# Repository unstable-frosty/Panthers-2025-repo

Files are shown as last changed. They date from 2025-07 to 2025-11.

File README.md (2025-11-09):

# Table of contents

- [Introduction](#Introduction)
- <a href="https://github.com/unstable-frosty/Panthers-2025-repo/tree/main/models">3D Models</a>
- <a href="https://github.com/unstable-frosty/Panthers-2025-repo/tree/main/schemes">Schematics</a>
- <a href="https://github.com/unstable-frosty/Panthers-2025-repo/tree/main/src">Coding Documentation</a>
- <a href="https://github.com/unstable-frosty/Panthers-2025-repo/blob/main/Development%20stages%20and%20work%20ethic.md">Development Stages and Work Ethic</a>
- <a href="https://github.com/unstable-frosty/Panthers-2025-repo/blob/main/Final%20plan%20strategy.md">Final plan strategy</a>
- <a href="https://github.com/unstable-frosty/Panthers-2025-repo/tree/main/v-photos">Car photos</a>
- <a href="https://github.com/unstable-frosty/Panthers-2025-repo/tree/main/t-photos">Team photos</a>

---

# Introduction
Hello everyone! 
Welcome to our GitHub repository. In this repo, we will be documenting our journey in building our obstacle avoiding car, while also sharing some details about our software, design struggles and how we managed to overcome these challenges. We hope to inspire everyone who reads this documentation and spark an idea for their future solutions. Thank you for your visit, enjoy the ride!

***

## Team members

Our team is made up of twin brothers **Kareem** and **Adam** with our mum, **Coach Ebtisam**, keeping us organized and moving forward.

> ### Kareem Siblini  
> **Age:** 16  
> **Role:** Design • Documentation • System integration  
> 
> I’m mostly responsible for the robot’s design, documentation, and wiring, but my brother and I always jump in to help each other whenever we need it. I’m really passionate about coding and cybersecurity, and I love using that interest to push our robot further. When I’m not working on the robot, you’ll usually find me playing basketball. This is my first year competing internationally in the WRO and my first time in the Future Engineers category, and I’m super excited to be here!

---

> ### Adam Siblini  
> **Age:** 16  
> **Role:** Coding • Algorithm & logic development
> 
> I’m mostly in charge of the coding and logic development for our robot, but just like Kareem helps me out, I also jump in to support his work whenever needed. I really enjoy math and love using it to build smarter algorithms for our robot. Outside of robotics, I enjoy swimming and staying active. This is my first year competing internationally in the WRO and my first time in the Future Engineers category, and I’m excited to take on the challenge!

---

> ### Coach Ebtisam Nassif  
> **Role:** Coach • Organization • Budget & components  

> I’m the coach of the team and also the mum of these twin brothers. I help keep everything on track: organizing, motivating, and stepping in when things get complicated so we can break problems down and solve them together. I’m also the one managing the budget and ordering the components we need, making sure the boys have what they need to keep building and improving. My role is to support them, keep things balanced, and guide them forward whenever things get overwhelming.

***

# Briefing

Our robot is an autonomous EV3 based car programmed in CLEV3R and powered by a coordinated multi sensor system. Three ultrasonic sensors connected through a MindSensors multiplexer provide continuous distance data, while a Pixy camera handles traffic sign color recognition, an EV3 color sensor detects checkpoints, and a gyro maintains accurate orientation by tracking the robot’s angle in real time. Together, these sensors give the robot reliable awareness of its surroundings and consistent interpretation of field elements.

The drivetrain uses EV3 medium motors driving a differential gear layout for smooth forward motion, paired with a custom parallel steering mechanism controlled by an EV3 medium motor. After multiple prototype iterations, this setup delivered the most stable turning, strong look ahead behavior, and minimal oscillation. The final design combines refined mechanical tuning with structured CLEV3R logic, resulting in a compact, responsive, and competition ready Future Engineers robot.

***

# Final Reflection

To sum this all up, we have put a great amount of work and dedication into this project, and despite the challenges that we have faced throughout, we believe that it was very helpful and insightful, as we learned a lot about new algorithms and mechanisms. We would like to thank our Coach (AKA mum). We would like to apologize to our coach for conquering the house with the map and all the Lego pieces :).

***

## 📬 Contact Us (**Email**)

<p align="center">
  <a href="mailto:Kareemsiblini@gmail.com"><strong>Kareem Siblini</strong></a> •
  <a href="mailto:adamsiblini@gmail.com"><strong>Adam Siblini</strong></a> •
  <a href="mailto:enassif@gmail.com"><strong>Coach Ebtisam Nassif</strong></a>
</p>

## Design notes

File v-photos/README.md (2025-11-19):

# Vehicle Photos
<p>In this directory, are 6 photos of the robot containing all 6 sides including our old prototypes right <a href="https://github.com/unstable-frosty/Panthers-2025-repo/tree/main/v-photos/Old%20prototype">here</a> enjoy :)</p>

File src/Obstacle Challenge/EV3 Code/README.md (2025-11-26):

# WRO Future Engineers – EV3 Navigation + Obstacle Avoidance

It is intended for:
- Future team members learning how the robot works  
- Judges or mentors reviewing the implementation  
- Anyone who wants to extend, debug, or port this logic to another platform  

The document is split into:
1. Project structure and imports  
2. Global variables and system state  
3. Ultrasonic distance thread  
4. Gyro + camera thread (Arduino bridge)  
5. Initialization and steering alignment  
6. Direction selection and initial rotation  
7. Main navigation loop (with obstacle avoidance)  
8. Color-based turning logic  
9. End-phase sequence  
10. Full source code  

---

## 1. Project Structure and Module Imports

The program begins by declaring the project folder and importing the custom modules that provide sensor and motion utilities:

```vb
folder "prjs""Clever"
import "Mods\HTColorV2"
import "Mods\arduino"
import "Mods\CAR"
import "Mods\Ultrasonic"
import "Mods\Tool"
```

### Module overview

- **HTColorV2**  
  Provides robust RGB readings and color classification. It is used to detect the orange and blue markers on the field that trigger 90° turns.

- **arduino**  
  Handles communication with an Arduino that sends:
  - Gyro yaw (`yawC`)
  - Camera error (`camError`)
  - Object signature (`sig`)
  - Bounding box information (`mcx`, `mcy`, `mw`, `mh`)  

  This allows the EV3 to use an external IMU + camera as if they were native sensors.

- **CAR**  
  A high-level motion library that encapsulates:
  - Steering control and centering
  - Gyro-based straight driving (`update_gyro_control`)
  - Combined gyro + distance wall following (`update_gyro_dis`)
  - Low-pass filters for noisy signals
  - Camera-based obstacle avoidance helper (`OB_AV`)

- **Ultrasonic**  
  Provides distance readings in centimeters from ultrasonic sensors on ports 2 and 4. These are used both for wall following and emergency “side yank” escape maneuvers.

- **Tool**  
  A collection of helper utilities (timing, math, etc.) that support the rest of the system.

By isolating hardware-specific logic into modules, the main script can focus on strategy instead of raw motor commands.

---

## 2. Global Variables and System State

Next, the program declares a set of global variables that are shared between the main code and the threads. They store the current navigation state, filtered sensor values, and controller memory.

```vb
cw = 3
gyro = 0
Ldistance = 0
Rdistance = 0
t_count = 0
target = 0
DIR = 0
t_distance = 40
repeat_straight = 0
con = 0
' loop counter for obstacle low-pass reset
ob_count = 0
```

### Navigation and distance state

- **`cw`** – direction mode  
  - `3` = not yet decided  
  - `0` or `1` = fixed direction (CCW vs CW) chosen based on walls

- **`gyro`** – filtered gyro heading used by the PID controllers.

- **`target`** – desired heading in degrees. Every time the robot performs a 90° turn, this value is increased or decreased by 90.

- **`t_count`** – number of 90° turns that have already been executed. The main loop runs until `t_count = 12`.

- **`Ldistance`, `Rdistance`** – current filtered distances from the ultrasonic sensors on the left and right.

- **`t_distance`** – target wall distance for the combined gyro + distance controller.

- **`DIR`** – auxiliary direction flag used inside the CAR library for wall-following logic.

- **`repeat_straight`** – used during initialization to repeatedly drive straight and settle mechanical slack in the steering linkage.

- **`con`** – a flag originally used for beeping logic, still available for diagnostics.

- **`ob_count`** – a loop counter passed into the obstacle avoidance function to allow periodic internal resets.

```vb
' ===== camera / obstacle variables =====
yawC = 0
camError = 0
sig = 6         ' 6 = no obstacle, anything else = obstacle / object
mcx = 0
mcy = 0
mw = 0
mh = 0

' gyro raw values
gyroRaw = 0
rawGyro = 0

' ===== obstacle avoidance controller state =====
ob_kp = 1.23
ob_kd = 8.1
ob_corr = 0
ob_old_err = 0
```

### Camera and obstacle variables

These are all updated by the Arduino thread:

- **`yawC`** – raw yaw angle from the external IMU (as an integer scaled by 100).
- **`camError`** – horizontal camera error of the tracked object relative to the center of the image (used for steering).
- **`sig`** – signature or mode from the camera system.  
  - `6` = *no obstacle present*  
  - any other value = *object detected* in front of the robot.
- **`mcx`, `mcy`** – center of the obstacle bounding box.
- **`mw`, `mh`** – width and height of the obstacle bounding box.

### Gyro raw values

- **`gyroRaw`**, **`rawGyro`** – intermediate variables used in filtering the gyro signal.

### Obstacle avoidance controller

- **`ob_kp`, `ob_kd`** – proportional and derivative gains for the camera-based obstacle avoidance PID.
- **`ob_corr`** – current correction output.
- **`ob_old_err`** – previous error value, used to calculate the derivative term.

By organizing the system state in this way, the robot can combine gyro, ultrasonic, and camera information to produce smooth and robust behavior.

---

## 3. Ultrasonic Sensor Thread

The ultrasonic sensors are read continuously in a dedicated thread. This ensures that distance data is always fresh, even when the main loop is busy with other tasks like turning or obstacle avoidance.

```vb
Sub ReadUltrasonic
  alphaDist = 0.9
  counter = 0

  ' Initialize once
  Ultrasonic.getCm(2, Ldistance)
  Ultrasonic.getCm(4, Rdistance)

  While 1=1
    Ultrasonic.getCm(2, rawLdistance)
    Ultrasonic.getCm(4, rawRdistance)

    CAR.lowpass(rawLdistance, Ldistance, alphaDist, Ldistance)
    CAR.lowpass(rawRdistance, Rdistance, alphaDist, Rdistance)

    ' Reset every 5 loops
    counter = counter + 1
    If counter >= 5 Then
      Ldistance = rawLdistance
      Rdistance = rawRdistance
      counter = 0
    EndIf

  EndWhile
EndSub
```

### How it works

1. **Initialization**  
   The first distance readings from ports 2 and 4 are stored in `Ldistance` and `Rdistance`.

2. **Continuous loop**  
   Inside the `While 1=1` loop, the thread:
   - Reads raw distances into `rawLdistance` and `rawRdistance`.
   - Passes them through a low-pass filter using `CAR.lowpass`:
     - This smooths out short spikes and noise.
   - Increments `counter`, and every 5 iterations it *resets* the filtered values to the raw readings.

3. **Why reset the filter periodically?**  
   Over time, a low-pass filter can lag behind sudden real changes. By forcing a reset every few cycles, the robot:
   - Retains the benefits of smoothing.
   - Avoids large delays when an obstacle suddenly appears or disappears.

This thread feeds stable distance data to:
- the wall-following controller, and
- the emergency side-escape logic.

---

## 4. Gyro + Camera Thread (Arduino Bridge)

The second background thread reads both gyro and camera data from the Arduino using a single call, `arduino.ReadArduinoFull`. This keeps orientation and visual information synchronized and up to date.

```vb
Sub ReadGyro
  alphaGyro = 0.6
  counter = 0

  ' Initialize once using Arduino full data (gyro + camera)
  arduino.ReadArduinoFull(1, yawC, camError, sig, mcx, mcy, mw, mh)
  gyroRaw = yawC
  gyro = (gyroRaw / 100) - offset

  While 1=1
    ' Read full data: yaw + camera information
    arduino.ReadArduinoFull(1, yawC, camError, sig, mcx, mcy, mw, mh)
    rawGyro = (yawC / 100) - offset

    ' Apply low-pass filter (same logic as before)
    CAR.lowpass2(rawGyro, gyro, alphaGyro, gyro)

    ' Reset filter every 10 loops (same logic as before)
    counter = counter + 1
    If counter >= 10 Then
      gyro = rawGyro        ' reset to current sensor reading
      counter = 0
    EndIf

  EndWhile
EndSub
```

### Step-by-step behavior

1. **Initial read**  
   - The thread calls `arduino.ReadArduinoFull` once to populate:
     - `yawC` (gyro yaw)
     - `camError`, `sig`, `mcx`, `mcy`, `mw`, `mh` (camera data)
   - It converts `yawC` (which is scaled by 100) into degrees and subtracts `offset` to define the current heading as zero.

2. **Continuous loop**  
   Inside the infinite loop:
   - `ReadArduinoFull` is called repeatedly to update all gyro + camera values.
   - The raw yaw (`rawGyro`) is converted to degrees and filtered using `CAR.lowpass2`.
   - Every 10 iterations, the filtered `gyro` is reset to the raw value to remove accumulated filtering bias.

3. **Why combine gyro and camera in one thread?**  
   - Both signals are time-critical.
   - Using a single read call keeps them synchronized and lowers communication overhead.
   - The main loop always has access to recent gyro and obstacle data without blocking.

This thread is critical for:
- Heading control (straight driving and turning)
- Camera-based obstacle avoidance
- Final end-phase diagnostics (printing the final angle)

---

## 5. Beep Thread (Optional Diagnostic)

There is an optional `beep` thread that can be used for acoustic feedback when certain conditions are met.

```vb
Sub beep
  LCD.Clear()
  While 1=1
    If con = 1 Then
      Speaker.Tone(100, 500, 100)
    EndIf
  EndWhile
EndSub
```

Currently, the line that starts this thread is commented out, so it is not active in the main behavior. However, it is useful for debugging:
- Setting `con = 1` in specific situations can make the robot beep continuously, signaling a particular mode or condition.

---

## 6. Initialization and Steering Alignment

Before starting complex navigation, the robot performs several initialization steps:

```vb
LCD.Clear()
''''''''''''''''''''''centering steering position'''''''''''''''''''''''
CAR.reset_gyro(offset)
Program.Delay(300)
CAR.center_steer(centerPos)
Program.Delay(50)

While repeat_straight < 1000
  CAR.move_steering(centerPos,0,lasterror)
  repeat_straight = repeat_straight+1
EndWhile
```

### What happens here

1. **Clear display**  
   The LCD is cleared so that any upcoming debug messages can be seen clearly.

2. **Gyro reset**  
   `CAR.reset_gyro(offset)` calibrates and stores a gyro offset so that the current physical orientation becomes the zero-degree reference.

3. **Center steering**  
   `CAR.center_steer(centerPos)` mechanically centers the steering motor, defining the neutral steering position (`centerPos`).

4. **Steering “settling”**  
   The robot repeatedly calls `CAR.move_steering(centerPos, 0, lasterror)` 1000 times:
   - This moves the steering into the centered position under closed-loop control.
   - It helps to remove mechanical slack or backlash.

This initialization step improves:
- Straight-line accuracy  
- Turn repeatability  
- Overall consistency between runs  

---

## 7. Starting the Sensor Threads

Once initialization is complete, the program starts both sensor threads:

```vb
LCD.Clear()
Program.Delay(100)
Thread.Run = ReadUltrasonic
Thread.Run = ReadGyro
'Thread.Run = beep
Program.Delay(100)
```

- `ReadUltrasonic` continuously updates `Ldistance` and `Rdistance`.
- `ReadGyro` continuously updates `gyro`, `camError`, `sig`, and bounding box data.
- The `beep` thread can be enabled by uncommenting its line if needed.

The short delays (`Program.Delay(100)`) give the threads time to start and begin populating global variables.

---

## 8. Direction Selection and Initial Rotation

Before the main navigation loop, the robot chooses whether it will navigate in a clockwise or counter-clockwise pattern, based on the initial distances to the walls:

```vb
'''''''''''''''''''''''''''''''''determine direction''''''''''''''''''
If Ldistance > Rdistance Then
  cw = 0
Else 
  cw = 1
EndIf
```

- If the left wall is farther than the right (`Ldistance > Rdistance`), then `cw = 0`.
- Otherwise, `cw = 1`.

This provides an automatic way to decide which side of the corridor to follow.

Next, the robot performs a short backward motion and a 90° rotation using gyro control:

```vb
Motor.ResetCount("C")
While Math.Abs(Motor.GetCount("C"))<400
  CAR.move_steering(centerPos,0,lasterror)
  Motor.StartPower("C",-50)
EndWhile
Motor.StartPower("C",0)
Speaker.Tone(100, 4000, 100)
Motor.ResetCount("C")
Motor.StartPower("C",50)
While Math.Abs(Motor.GetCount("C"))<550
  If cw = 0 Then
    CAR.update_gyro_control(90, 3, 8, 0,centerPos, gyro,filteredError,  gyroLastError)
  Else
    CAR.update_gyro_control(-90, 3, 8, 0,centerPos, gyro,filteredError,  gyroLastError)
  EndIf
EndWhile
Motor.StartPower("C",0)

Program.Delay(100)
Motor.StartPower("C",70)
```

### Breakdown

1. **Short backward movement**  
   - The robot drives backwards while keeping the steering centered.
   - This likely positions it correctly at the start line.

2. **Beep notification**  
   - After stopping, it plays a tone to indicate that the initial backing-up is complete.

3. **Initial 90° rotation**  
   - The robot drives forward while using `CAR.update_gyro_control` to rotate to:
     - +90° if `cw = 0`
     - −90° if `cw = 1`
   - This aligns the robot with the first corridor it will follow.

4. **Transition to normal speed**  
   - The drive motor is set to power 70, and the robot is ready to start the main navigation loop.

---

## 9. Main Navigation Loop (with Obstacle Avoidance)

The main loop runs until the robot has executed 12 turns:

```vb
While t_count<>12
  CAR.color_RGB(3,clr)

  ' ---------------------------------------
  ' Obstacle LPF loop counter
  ' Reset every 10 main-loop iterations
  ' ---------------------------------------
  ob_count = ob_count + 1
  If ob_count >= 10 Then
    ob_count = 0
  EndIf
```

At the start of each iteration:
- The color sensor on port 3 is read into `clr`.
- `ob_count` is incremented and reset every 10 loops (this value is passed into the obstacle avoidance routine for its own internal timing).

### 9.1 Camera-Based Obstacle Avoidance

If the Arduino reports that an obstacle is present (i.e., `sig <> 6`), the robot hands control to a dedicated obstacle avoidance routine in the CAR module:

```vb
  If sig <> 6 Then
    ' Use camera-based obstacle avoidance from CAR library
    ' NOTE: OB_AV signature (in CAR):
    ' OB_AV(centerPos, error, sig, count, mcx, mcy, mw, mh, kp, kd, corr, old_err)
    CAR.OB_AV(centerPos, camError, sig, ob_count, mcx, mcy, mw, mh, ob_kp, ob_kd, ob_corr, ob_old_err)
```

- `camError` tells the controller how far left or right the obstacle is.
- `mcx`, `mcy`, `mw`, `mh` give extra shape and position information.
- `ob_kp` and `ob_kd` define how aggressively the robot should respond.
- `ob_corr` and `ob_old_err` store internal state for the controller.

Within this branch, **the standard wall-following logic is temporarily suspended**, and the robot focuses purely on safe avoidance.

### 9.2 Ultrasonic “Side Yank” Escape Maneuvers

If there is **no camera obstacle** (`sig = 6`), the robot first checks for dangerous proximity to the side walls using the ultrasonic sensors:

```vb
  Else
    ' =====================================================
    ' Side ultrasonic "quick pull" logic with speed boost
    '   - If left < 5 cm  -> pull right (steering = 55)
    '   - If right < 5 cm -> pull left  (steering = -55)
    '   - During yank: speed = 100
    '   - After yank : speed = 70
    ' =====================================================

    If Ldistance < 5 Then
      Motor.StartPower("C",100)
      Motor.ResetCount("C")
      While Math.Abs(Motor.GetCount("C")) < 15
        CAR.move_steering(centerPos, -55, lastCombinedError)
      EndWhile
      Speaker.Tone(100, 4000, 100)
      Motor.StartPower("C",70)
    EndIf

    If Rdistance < 5 Then
      Motor.StartPower("C",100)
      Motor.ResetCount("C")
      While Math.Abs(Motor.GetCount("C")) < 15
        CAR.move_steering(centerPos, 55, lastCombinedError)

      EndWhile
      Speaker.Tone(100, 4000, 100)
      Motor.StartPower("C",70)
    EndIf
```

- If the **left** distance drops below 5 cm:
  - The robot briefly speeds up (`power = 100`) and steers strongly to the **right** (steering = −55).
- If the **right** distance drops below 5 cm:
  - The robot does the mirrored maneuver to the **left**.
- In both cases, a high-pitched beep is played as feedback, and the speed returns to 70 afterwards.

This logic acts as a last-second safety net against crashing into walls.

### 9.3 Normal Course-Keeping: Gyro + Distance Control

If there is no camera obstacle and no emergency side yank in progress, the robot uses its standard navigation logic:

```vb
    ' ================= ORIGINAL COURSE-KEEPING LOGIC =================
    If cw = 3 Then
      CAR.update_gyro_control(target, 0.5, 8, 0,centerPos, gyro,filteredError,  gyroLastError)
      con = 1
    Else
      con = 0
      CAR.select(cw,Rdistance,Ldistance,distance)
      If cw = 0 And target-gyro>30 Then
        'Motor.StartPower("C", 100)
        CAR.update_gyro_control(target, 1.2, 12 , 0,centerPos, gyro,filteredError,  gyroLastError)
      ElseIf cw = 1 And target - gyro < -30 Then
        'Motor.StartPower("C", 100)
        CAR.update_gyro_control(target, 1.2, 12 , 0,centerPos, gyro,filteredError,  gyroLastError)
      Else
        'Motor.StartPower("C", 50)
        CAR.update_gyro_dis(cw,target,gyro, t_distance, 1.2, 6, 1.5,6,centerPos,distance,gyroError,distError,lastCombinedError,DIR)
      EndIf
    EndIf
    ' ================= END ORIGINAL COURSE-KEEPING LOGIC =================
  EndIf
```

#### Behavior in detail

- If `cw = 3`, the direction hasn’t been fixed yet:
  - The robot simply uses `update_gyro_control` to stay near the `target` heading with gentle parameters.

- If `cw` is 0 or 1 (direction chosen):
  - `CAR.select(cw, Rdistance, Ldistance, distance)` decides which wall to use for wall-following and stores it in `distance`.
  - If the heading error is large (more than 30° in the direction that matters for `cw`), the robot uses a strong pure gyro controller:
    - `CAR.update_gyro_control(target, 1.2, 12, ...)`
  - Otherwise, it uses combined gyro + distance control:
    - `CAR.update_gyro_dis(...)`
    - This keeps the robot at a stable distance from the chosen wall **and** aligned with the overall desired heading.

This layered control gives:
- Strong corrections when badly misaligned.
- Smooth, balanced tracking of both heading and wall distance in normal conditions.

---

## 10. Color-Based Turning Logic

Within the same main loop, color markers trigger 90° turns. The robot only reacts to a color if it matches the chosen direction mode `cw`:

```vb
  If clr = 2 And cw =1 Then '''''''''orange(CW)'''''''''
    Speaker.Tone(100, 2000, 100)
    'Program.Delay(250)
    Motor.ResetCount("C")
    While Math.Abs(Motor.GetCount("C"))<50
      CAR.move_steering(centerPos,0,lastCombinedError)
    EndWhile
    target = target - 90
    t_count = t_count+1

  ElseIf clr = 3 And cw = 0 Then'''''''''''BLUE(CCW)'''''''''''''''
    Speaker.Tone(100, 2000, 100)
    'Program.Delay(250)
    Motor.ResetCount("C")
    While Math.Abs(Motor.GetCount("C"))<50
      CAR.move_steering(centerPos,0,lastCombinedError)
    EndWhile
    target = target + 90
    t_count = t_count+1
  EndIf
```

### Color roles

- **Orange (`clr = 2`) + `cw = 1`**  
  → Robot commits to a **clockwise** 90° turn by setting `target = target - 90`.

- **Blue (`clr = 3`) + `cw = 0`**  
  → Robot commits to a **counter-clockwise** 90° turn by setting `target = target + 90`.

In both cases:
1. The robot drives straight a short encoder distance (50 counts) to pass the color marker.
2. Then adjusts `target` by ±90 degrees.
3. Increments `t_count`, moving to the next navigation segment.

The actual physical rotation toward the new `target` is handled by the gyro-based control in the normal course-keeping logic.

Once `t_count` reaches 12, the main loop ends and the robot enters its end-phase sequence.

---

## 11. End-Phase Sequence

After all 12 turns are completed, the robot performs a carefully structured end-phase:

```vb
''''''''''''''''''''''''''''''END PHASE'''''''''''''''''''''''
Motor.ResetCount("C")
While Math.Abs(Motor.GetCount("C"))<255
  CAR.move_steering(centerPos,0,lastCombinedError)
EndWhile

Motor.ResetCount("C")
Time.Reset2()
While Math.abs(MotorC.GetTacho())<1000 Or Time.Get2()<4
  CAR.update_gyro_control(target, 1.2, 12 , 0,centerPos, gyro,filteredError,  gyroLastError)
EndWhile

While Math.abs(MotorC.GetTacho())<3100 Or Time.Get2()<4
  CAR.select(cw,Rdistance,Ldistance,distance)
  CAR.update_gyro_dis(cw,target,gyro, t_distance, 1.2, 6, 1.5,6,centerPos,distance,gyroError,distError,lastCombinedError,DIR)
EndWhile

LCD.Clear()
LCD.Text(1, 0, 0, 2, "Angle: " + gyro)
Motor.StartPower("C", 0)
Program.Delay(200000)
```

### Phases

1. **Short straight segment**  
   - The robot drives straight for 255 encoder counts with neutral steering.
   - This stabilizes the motion after the last turn.

2. **Gyro-only correction segment**  
   - The robot drives while `update_gyro_control` tries to match the final `target`.
   - This continues until either:
     - the tacho count reaches about 1000, or
     - 4 seconds have passed.
   - This step maximizes heading accuracy.

3. **Gyro + distance final approach**  
   - The robot then uses `update_gyro_dis` again, combining gyro and wall distance.
   - This continues until either:
     - the tacho count reaches about 3100, or
     - 4 seconds have passed.
   - This keeps the robot aligned and at the correct lateral position near the finish.

4. **Diagnostic display and stop**  
   - The LCD is cleared and the final gyro angle is printed (`"Angle: " + gyro`).
   - Motor C is stopped.
   - `Program.Delay(200000)` keeps the program alive so the result can be inspected.

This end-phase is designed to deliver a clean, stable final pose with a readable final heading.

---

## 12. Full Source Code

Below is the complete program exactly as used for the robot.  
You can copy-paste this into Clev3r to reproduce the behavior.

```vb
folder "prjs""Clever"
import "Mods\HTColorV2"
import "Mods\arduino"
import "Mods\CAR"
import "Mods\Ultrasonic"
import "Mods\Tool"

''''''''''''''''''''''variable declaration'''''''''''''''''''
cw = 3
gyro = 0
Ldistance = 0
Rdistance = 0
t_count = 0
target = 0
DIR = 0
t_distance = 40
repeat_straight = 0
con = 0
' loop counter for obstacle low-pass reset
ob_count = 0

' ===== camera / obstacle variables =====
yawC = 0
camError = 0
sig = 6         ' 6 = no obstacle, anything else = obstacle / object
mcx = 0
mcy = 0
mw = 0
mh = 0

' gyro raw values
gyroRaw = 0
rawGyro = 0

' ===== obstacle avoidance controller state =====
ob_kp = 1.23
ob_kd = 8.1
ob_corr = 0
ob_old_err = 0

''''''''''''''''''''''sub to read ultrasonic'''''''''''''''''''''''
Sub ReadUltrasonic
  alphaDist = 0.9
  counter = 0

  ' Initialize once
  Ultrasonic.getCm(2, Ldistance)
  Ultrasonic.getCm(4, Rdistance)

  While 1=1
    Ultrasonic.getCm(2, rawLdistance)
    Ultrasonic.getCm(4, rawRdistance)

    CAR.lowpass(rawLdistance, Ldistance, alphaDist, Ldistance)
    CAR.lowpass(rawRdistance, Rdistance, alphaDist, Rdistance)

    ' Reset every 5 loops
    counter = counter + 1
    If counter >= 5 Then
      Ldistance = rawLdistance
      Rdistance = rawRdistance
      counter = 0
    EndIf

  EndWhile
EndSub

''''''''''''''''''''''sub to read gyro (using ReadArduinoFull)'''''''''''''''''''''''
Sub ReadGyro
  alphaGyro = 0.6
  counter = 0

  ' Initialize once using Arduino full data (gyro + camera)
  arduino.ReadArduinoFull(1, yawC, camError, sig, mcx, mcy, mw, mh)
  gyroRaw = yawC
  gyro = (gyroRaw / 100) - offset

  While 1=1
    ' Read full data: yaw + camera information
    arduino.ReadArduinoFull(1, yawC, camError, sig, mcx, mcy, mw, mh)
    rawGyro = (yawC / 100) - offset

    ' Apply low-pass filter (same logic as before)
    CAR.lowpass2(rawGyro, gyro, alphaGyro, gyro)

    ' Reset filter every 10 loops (same logic as before)
    counter = counter + 1
    If counter >= 10 Then
      gyro = rawGyro        ' reset to current sensor reading
      counter = 0
    EndIf

  EndWhile
EndSub

Sub beep
  LCD.Clear()
  While 1=1
    If con = 1 Then
      Speaker.Tone(100, 500, 100)
    EndIf
  EndWhile
EndSub

LCD.Clear()
''''''''''''''''''''''centering steering position'''''''''''''''''''''''
CAR.reset_gyro(offset)
Program.Delay(300)
CAR.center_steer(centerPos)
Program.Delay(50)

While repeat_straight < 1000
  CAR.move_steering(centerPos,0,lasterror)
  repeat_straight = repeat_straight+1
EndWhile

''''''''''''''''''''''start sensor threads''''''''''''''''

LCD.Clear()
Program.Delay(100)
Thread.Run = ReadUltrasonic
Thread.Run = ReadGyro
'Thread.Run = beep
Program.Delay(100)

'''''''''''''''''''''''''''''''''determine direction''''''''''''''''''
If Ldistance > Rdistance Then
  cw = 0
Else 
  cw = 1
EndIf
Motor.ResetCount("C")
While Math.Abs(Motor.GetCount("C"))<400
  CAR.move_steering(centerPos,0,lasterror)
  Motor.StartPower("C",-50)
EndWhile
Motor.StartPower("C",0)
Speaker.Tone(100, 4000, 100)
Motor.ResetCount("C")
Motor.StartPower("C",50)
While Math.Abs(Motor.GetCount("C"))<550
  If cw = 0 Then
    CAR.update_gyro_control(90, 3, 8, 0,centerPos, gyro,filteredError,  gyroLastError)
  Else
    CAR.update_gyro_control(-90, 3, 8, 0,centerPos, gyro,filteredError,  gyroLastError)
  EndIf
EndWhile
Motor.StartPower("C",0)

Program.Delay(100)
Motor.StartPower("C",70)

'''''''''''''''''''''''''''''''''''''''''''''''''''''''''''''
While t_count<>12
  CAR.color_RGB(3,clr)

  ' ---------------------------------------
  ' Obstacle LPF loop counter
  ' Reset every 10 main-loop iterations
  ' ---------------------------------------
  ob_count = ob_count + 1
  If ob_count >= 10 Then
    ob_count = 0
  EndIf

  ' =====================================================
  ' Obstacle avoidance:
  '   sig = 6  -> no obstacle   (follow original logic)
  '   sig <> 6 -> obstacle      (use CAR.OB_AV)
  ' =====================================================
  If sig <> 6 Then
    ' Use camera-based obstacle avoidance from CAR library
    ' NOTE: OB_AV signature (in CAR):
    ' OB_AV(centerPos, error, sig, count, mcx, mcy, mw, mh, kp, kd, corr, old_err)
    CAR.OB_AV(centerPos, camError, sig, ob_count, mcx, mcy, mw, mh, ob_kp, ob_kd, ob_corr, ob_old_err)
  Else
    ' =====================================================
    ' Side ultrasonic "quick pull" logic with speed boost
    '   - If left < 5 cm  -> pull right (steering = 55)
    '   - If right < 5 cm -> pull left  (steering = -55)
    '   - During yank: speed = 100
    '   - After yank : speed = 70
    ' =====================================================

    If Ldistance < 5 Then
      Motor.StartPower("C",100)
      Motor.ResetCount("C")
      While Math.Abs(Motor.GetCount("C")) < 15
        CAR.move_steering(centerPos, -55, lastCombinedError)
      EndWhile
      Speaker.Tone(100, 4000, 100)
      Motor.StartPower("C",70)
    EndIf

    If Rdistance < 5 Then
      Motor.StartPower("C",100)
      Motor.ResetCount("C")
      While Math.Abs(Motor.GetCount("C")) < 15
        CAR.move_steering(centerPos, 55, lastCombinedError)

      EndWhile
      Speaker.Tone(100, 4000, 100)
      Motor.StartPower("C",70)
    EndIf

    ' ================= ORIGINAL COURSE-KEEPING LOGIC =================
    If cw = 3 Then
      CAR.update_gyro_control(target, 0.5, 8, 0,centerPos, gyro,filteredError,  gyroLastError)
      con = 1
    Else
      con = 0
      CAR.select(cw,Rdistance,Ldistance,distance)
      If cw = 0 And target-gyro>30 Then
        'Motor.StartPower("C", 100)
        CAR.update_gyro_control(target, 1.2, 12 , 0,centerPos, gyro,filteredError,  gyroLastError)
      ElseIf cw = 1 And target - gyro < -30 Then
        'Motor.StartPower("C", 100)
        CAR.update_gyro_control(target, 1.2, 12 , 0,centerPos, gyro,filteredError,  gyroLastError)
      Else
        'Motor.StartPower("C", 50)
        CAR.update_gyro_dis(cw,target,gyro, t_distance, 1.2, 6, 1.5,6,centerPos,distance,gyroError,distError,lastCombinedError,DIR)
        'CAR.update_gyro_control(target, 1.2, 12 , 0,centerPos, gyro,filteredError,  gyroLastError)
      EndIf
    EndIf
    ' ================= END ORIGINAL COURSE-KEEPING LOGIC =================
  EndIf

  If clr = 2 And cw =1 Then '''''''''orange(CW)'''''''''
    Speaker.Tone(100, 2000, 100)
    'Program.Delay(250)
    Motor.ResetCount("C")
    While Math.Abs(Motor.GetCount("C"))<50
      CAR.move_steering(centerPos,0,lastCombinedError)
    EndWhile
    target = target - 90
    t_count = t_count+1

  ElseIf clr = 3 And cw = 0 Then'''''''''''BLUE(CCW)'''''''''''''''
    Speaker.Tone(100, 2000, 100)
    'Program.Delay(250)
    Motor.ResetCount("C")
    While Math.Abs(Motor.GetCount("C"))<50
      CAR.move_steering(centerPos,0,lastCombinedError)
    EndWhile
    target = target + 90
    t_count = t_count+1
  EndIf

EndWhile

''''''''''''''''''''''''''''''END PHASE'''''''''''''''''''''''
Motor.ResetCount("C")
While Math.Abs(Motor.GetCount("C"))<255
  CAR.move_steering(centerPos,0,lastCombinedError)
EndWhile

Motor.ResetCount("C")
Time.Reset2()
While Math.abs(MotorC.GetTacho())<1000 Or Time.Get2()<4
  CAR.update_gyro_control(target, 1.2, 12 , 0,centerPos, gyro,filteredError,  gyroLastError)
EndWhile

While Math.abs(MotorC.GetTacho())<3100 Or Time.Get2()<4
  CAR.select(cw,Rdistance,Ldistance,distance)
  CAR.update_gyro_dis(cw,target,gyro, t_distance, 1.2, 6, 1.5,6,centerPos,distance,gyroError,distError,lastCombinedError,DIR)
EndWhile

LCD.Clear()
LCD.Text(1, 0, 0, 2, "Angle: " + gyro)
Motor.StartPower("C", 0)
Program.Delay(200000)
```

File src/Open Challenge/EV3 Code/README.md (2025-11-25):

# EV3 Open Challenge Code Explanation

This document explains the navigation program for the WRO Future Engineers Open Challenge.

---

## 1. Project Structure and Module Imports

The program begins by declaring the project folder and importing several specialized modules. These modules collectively provide the robot with the ability to sense its environment, perform stable motion, communicate with an external gyro interface, and apply advanced control techniques. Instead of writing raw motor logic repeatedly throughout the code, these imported modules encapsulate reusable behaviors such as wall-following, low-pass filtering, steering alignment, and color recognition. Loading them at the beginning enables the main script to operate at a high level, focusing on navigation strategy rather than low-level commands.

```vb
folder "prjs""Clever"
  import "Mods\HTColorV2"
  import "Mods\arduino"
  import "Mods\CAR"
  import "Mods\Ultrasonic"
  import "Mods\Tool"
```

### Key capabilities added by these imports:
- More stable RGB detection for colored markers  
- Precise gyro readings from an Arduino bridge  
- Steering and PID utilities for straight driving and turning  
- Real-time ultrasonic handling  
- General helper functions used across multiple subsystems  

These imports define the environment in which the robot will operate during the challenge.

---

## 2. Global Variables and System State

After loading the required modules, the program initializes a set of global variables. These variables act as a shared memory space that both the main logic and background threads can access. They store sensor readings, operational modes, counters, and target heading values. Because the robot must move through twelve navigation segments with precise turns and dynamic behaviors, these variables allow different parts of the program to coordinate and maintain consistent behavior across time.

```vb
cw = 3
gyro = 0
Ldistance = 0
Rdistance = 0
t_count = 0
target = 0
DIR = 0
t_distance = 30
repeat_straight = 0
```

### These variables represent:
- **Navigation mode** (neutral, clockwise, counter‑clockwise)  
- **Heading** (filtered gyro angle)  
- **Distance to walls** on left and right  
- **Turn counter** which ensures exactly 12 turns  
- **Desired heading target** for gyro control  
- **Preferred wall distance** for wall‑following  
- **Steering alignment buffer** during initialization  

This shared state gives the robot a consistent reference throughout the entire run.

---

## 3. Ultrasonic Sensor Thread

The ultrasonic thread continuously reads the left and right distance sensors in the background. This design ensures the robot always has fresh distance data even when the main loop is busy performing steering updates or evaluating turn logic. Because ultrasonic sensors can produce noisy readings, the thread smooths the values using a low‑pass filter. This prevents sudden changes from destabilizing the robot during wall‑following.

```vb
Sub ReadUltrasonic
  alphaDist = 0.9
  counter = 0
  Ultrasonic.getCm(2, Ldistance)
  Ultrasonic.getCm(4, Rdistance)
  While 1=1
    Ultrasonic.getCm(2, rawLdistance)
    Ultrasonic.getCm(4, rawRdistance)
    CAR.lowpass(rawLdistance, Ldistance, alphaDist, Ldistance)
    CAR.lowpass(rawRdistance, Rdistance, alphaDist, Rdistance)
    counter = counter + 1
    If counter >= 5 Then
      Ldistance = rawLdistance
      Rdistance = rawRdistance
      counter = 0
    EndIf
  EndWhile
EndSub
```

### Why this is important:
- Ultrasonic noise is reduced before being used for steering  
- Filtering prevents “twitchy” corrections  
- Periodic resets ensure the sensor doesn’t accumilate error
- Continuous looping ensures high update frequency  

This thread allows the robot to rely confidently on wall distance measurements.

---

## 4. Gyro Thread Through Arduino

The gyro thread performs a similar role but focuses on angular heading. It gathers angle information from the Arduino gyro bridge, applies smoothing, and periodically resets the filter. Since the gyro reading is essential for straight driving and accurate 90° turns, this continuous background process ensures minimal drift and maximum responsiveness.

```vb
Sub ReadGyro
  alphaGyro = 0.6
  counter = 0
  arduino.GyroArduino(1, gyroRaw)
  gyro = (gyroRaw / 100) - offset
  While 1=1
    arduino.GyroArduino(1, gyroRaw)
    rawGyro = (gyroRaw / 100) - offset
    CAR.lowpass2(rawGyro, gyro, alphaGyro, gyro)
    counter = counter + 1
    If counter >= 10 Then
      gyro = rawGyro
      counter = 0
    EndIf
  EndWhile
EndSub
```

### Key benefits of the gyro thread:
- Smooth heading changes  
- Stable readings for PID control  
- Prevents drift buildup  
- Maintains constant orientation awareness during all segments  

Accurate heading data is fundamental to the robot’s navigation performance.

---

## 5. Initialization and Steering Alignment

Before entering the main navigation loop, the robot performs several important setup routines. It first resets and calibrates the gyro so that the initial heading becomes the zero-degree reference. The robot then centers the steering mechanism to ensure the wheels are aligned for straight driving. Because mechanical linkages can introduce slack or misalignment, the robot performs a repeated straight‑drive routine that physically settles the steering system into its true center. This helps ensure that the first long straight segment is accurate and reduces error accumulation later.

### The steps achieve:
- A reliable gyro baseline  
- Properly centered wheels  
- Removal of mechanical slack  
- A consistent starting movement pattern  

This preparation dramatically improves the repeatability of the robot’s navigation performance.

---

## 6. Main Navigation Loop

The main loop runs until the robot completes twelve navigation segments. Each cycle begins with reading the color sensor, followed by choosing between different steering behaviors. Initially, the robot drives straight using soft gyro control. Once a color marker is detected, the robot switches into its long‑term direction mode. From there, it uses either pure gyro correction or combined gyro‑distance correction depending on how far it has drifted from the target heading. Wall‑following uses both distance and heading error simultaneously, producing a balanced steering output that keeps the robot aligned to the wall while maintaining the correct overall direction.

### The main loop blends:
- Color detection  
- Gyro‑only correction  
- Wall‑following control  
- Large‑error heading correction  
- Turn detection and execution  

By switching intelligently between these behaviors, the robot adapts to environmental conditions while maintaining a predictable path.

---

## 7. Color‑Based Direction Selection

When the robot first sees orange or blue, it chooses whether to follow a clockwise or counter‑clockwise pattern for the rest of the run. This choice determines which wall the robot uses for guidance and in which direction each 90° turn will rotate. The logic only triggers once because the robot must commit to its direction for consistency.

### Color meaning:
- **Orange → Clockwise**  
- **Blue → Counter‑Clockwise**

This decision defines the robot’s navigation style for all remaining segments.

---

## 8. Performing 90° Turns

Each turn is triggered when the robot detects the appropriate color while already in its corresponding direction mode. Before turning, the robot drives forward a short encoder distance to clear the marker. It then adjusts the target heading by ±90°, depending on the direction. The gyro PID controller handles the rotation automatically, steering the robot to align itself with the new heading. After completing the turn, the robot increments the `t_count` variable to progress to the next navigation segment.

### Turn elements include:
- Color confirmation  
- Encoder‑based forward buffer  
- Target heading change  
- PID‑stabilized rotation  
- Segment count update  

This structured approach ensures predictable and repeatable turns.

---

## 9. End‑Phase Sequence

After completing all twelve turns, the robot enters a final sequence of movements. It first drives a short straight distance, then transitions to a longer gyro‑corrected segment(turn), and finally performs a wall‑following stretch. These layers help compensate for any drift accumulated earlier in the run and place the robot near the final area with consistent alignment. At the end, the robot displays its final gyro angle and stops the drive motor while leaving the program running so that we can inspect the result.

### This final section provides:
- A stabilizing straight movement  
- A long accurate gyro‑guided segment  
- A final wall‑corrected approach  
- A diagnostic display of heading  

This ensures the robot finishes cleanly and predictably.

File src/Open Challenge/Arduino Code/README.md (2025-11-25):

# Arduino → EV3 Gyro Bridge (BNO08x IMU)

This project turns an Arduino-compatible board (such as an ESP32) into a **virtual EV3 Gyro Sensor**. It reads orientation data from a **BNO08x IMU** and sends a **continuous yaw angle** to the LEGO Mindstorms EV3 over I²C. In practice, this allows you to use a modern, high-performance IMU as if it were an official EV3 gyro sensor, but with several advantages: it supports unlimited rotation (a continuous multi-turn angle), provides a high update rate, includes automatic error recovery, and offers a simple re-zero command. This makes it especially well suited for WRO and other open-category competitions where robustness and repeatability over long runs are critical.

---

# 1. Overview

At a high level, this firmware acts as a **protocol translator** between a modern IMU and the LEGO EV3 brick. On one side, it communicates with the **BNO08x** IMU using I²C and consumes its rotation vector (quaternion) output. On the other side, it behaves like a simple I²C sensor from the perspective of the EV3, exposing only a 4-byte signed value that represents the current heading.

The firmware continuously reads quaternion orientation from the BNO08x and converts that quaternion into a yaw angle in degrees. It then integrates small changes in yaw over time to produce a continuous turning angle that can grow beyond the usual −180°…+180° or −360° ranges. This continuous angle is maintained internally and, whenever the EV3 performs an I²C read, the firmware returns the current value as a 32-bit integer representing yaw in centi-degrees (angle × 100). From the EV3’s point of view, this looks like a highly capable gyro sensor that never “wraps around” during multi-turn rotations.

---

# 2. Hardware & Pin Configuration

```cpp
#define SLAVE_ADDRESS 0x04   // I²C address seen by the EV3

#define EV3_SDA 12           // EV3 I²C SDA pin on the Arduino/ESP32
#define EV3_SCL 11           // EV3 I²C SCL pin on the Arduino/ESP32

TwoWire EV3Wire = TwoWire(1); // I²C instance used for EV3 side

BNO08x imu;
uint8_t currentAddr = 0x4A;   // BNO08x I²C address (fallback to 0x4B)
const uint16_t reportIntervalMs = 20;
const uint32_t noDataTimeoutMs = 1000;
uint32_t lastEventMs = 0;
```

These definitions set up the core configuration of the system. The `SLAVE_ADDRESS` constant determines which I²C address the EV3 will use when talking to this board; from the EV3’s perspective, this looks like the address of a standard I²C sensor. The `EV3_SDA` and `EV3_SCL` constants specify which pins on the Arduino or ESP32 are physically connected to the EV3 sensor port for I²C communication, so they must match your wiring.

The `EV3Wire` object creates a dedicated I²C bus instance for the EV3 side, completely separate from the I²C bus used to talk to the IMU. This separation improves reliability and makes debugging easier because traffic to and from the EV3 cannot interfere directly with traffic to the IMU. The `imu` object represents the BNO08x sensor itself, while `currentAddr` stores the I²C address currently in use for that IMU, defaulting to `0x4A` but allowing a fallback to `0x4B` if necessary.

Finally, the timing-related variables `reportIntervalMs`, `noDataTimeoutMs`, and `lastEventMs` control how often the IMU provides data and how long the firmware will tolerate silence before concluding that communication has failed. Together, they form the foundation for the sensor’s automatic recovery mechanism.

---

# 3. Yaw State & Quaternion Helper Functions

```cpp
volatile float accumYaw = 0.0f;
float yawOffset = 0.0f;
float lastYaw = 0.0f;
bool firstYawSet = false;

volatile int lastCmd = 0;
volatile bool cmdReady = false;

static inline float rad2deg(float r) { return r * 180.0f / PI; }

static float quatToYawDeg(float w, float x, float y, float z) {
  float s = 2.0f * (w * z + x * y);
  float c = 1.0f - 2.0f * (y * y + z * z);
  return rad2deg(atan2f(s, c));
}
```

These variables and helper functions maintain the yaw-tracking state and handle quaternion math. The variable `accumYaw` holds the continuous yaw angle in degrees and can grow beyond a single revolution, representing the total net rotation since initialization or the last reset. The `yawOffset` value stores an initial yaw reference so that the first valid IMU reading becomes the logical zero angle for the robot. The `lastYaw` variable remembers the previous wrapped yaw reading, and `firstYawSet` indicates whether a valid yaw reference has been established yet.

The variables `lastCmd` and `cmdReady` implement a small command mailbox for the EV3. Whenever the EV3 writes a command byte to this sensor over I²C, the `receiveData()` callback stores it in `lastCmd` and sets `cmdReady` to `true`. The main loop then checks this flag and handles the command in a safe, non-interrupt context.

The function `rad2deg()` is a simple utility that converts radians to degrees, which keeps the rest of the code easier to read. The `quatToYawDeg()` function is responsible for extracting a yaw angle (in degrees) from a quaternion `(w, x, y, z)` provided by the IMU. It computes two intermediate values, `s` and `c`, using standard quaternion-to-Euler conversion formulas, and then calls `atan2f(s, c)` to obtain a yaw angle in radians before converting it to degrees.

---

# 4. IMU Reset, Configuration & Recovery

This part of the firmware is responsible for keeping the IMU alive and usable throughout a match, even when the environment is electrically noisy or cables are slightly unreliable. In competitive robotics, it is common for robots to experience brownouts, jerky cable movement, transient disconnections, or voltage dips when multiple motors start or stop at once. Without explicit handling of these cases, the IMU might freeze, reset internally, or stop producing data, which would make the yaw reading useless. The code in this section detects such problems and attempts to recover from them automatically.

## 4.1 Hardware Reset Placeholder

```cpp
void hwResetIfAvailable() {
  delay(300);  // placeholder for real hardware reset line if available
}
```

The `hwResetIfAvailable()` function is a placeholder for a potential hardware reset line connected to the BNO08x. Some breakout boards expose a dedicated reset pin that can be toggled by the microcontroller. Even if your board does not currently use a physical reset signal, this function provides a central place to add one later. For now, it simply introduces a brief delay, giving the IMU time to power-cycle or restart cleanly if a reset has occurred through other means.

## 4.2 IMU Report Configuration

```cpp
bool configureReports() {
  return imu.enableRotationVector(reportIntervalMs);
}
```

The IMU supports many different output report types, but this firmware is specifically interested in the **rotation vector**, which provides orientation as a fused quaternion. The `configureReports()` function enables this report at the interval specified by `reportIntervalMs`, which in this case is 20 milliseconds, corresponding to a 50 Hz update rate. This frequency is fast enough for smooth heading control on an EV3 robot, yet not so fast that it overloads the I²C bus or the microcontroller.

## 4.3 Starting the IMU (Initialization Sequence)

```cpp
bool startBNO() {
  bool ok = imu.begin(currentAddr, Wire, -1, -1);
  if (!ok) return false;

  configureReports();
  lastEventMs = millis();

  firstYawSet = false;
  accumYaw = 0.0f;
  lastYaw = 0.0f;

  return true;
}
```

The `startBNO()` function encapsulates the process of bringing the IMU into an operational state. It first calls `imu.begin()` with the current I²C address. If this fails, the function immediately returns `false`, signaling to the caller that the IMU could not be reached. If the call succeeds, the function then enables the rotation vector report, records the current time in `lastEventMs`, and resets the yaw state by clearing `accumYaw`, `lastYaw`, and `firstYawSet`. This ensures that each successful IMU startup begins from a known, consistent orientation reference.

## 4.4 Recovery Logic (Self-Healing)

```cpp
void recover() {
  hwResetIfAvailable();
  if (!startBNO()) {
    currentAddr = (currentAddr == 0x4A) ? 0x4B : 0x4A;
    hwResetIfAvailable();
    startBNO();
  }
}
```

The `recover()` function implements the self-healing behavior of the system. When called, it first performs a hardware reset delay by calling `hwResetIfAvailable()`, and then attempts to start the IMU using `startBNO()`. If that attempt fails, the code assumes that the IMU might be configured at the alternate I²C address, and it toggles `currentAddr` between `0x4A` and `0x4B`. It then calls the reset placeholder again and performs another attempt to start the IMU. In practice, this sequence allows the system to recover from transient faults, cable issues, or incorrect address assumptions without manual intervention. For a competition robot, this kind of automatic recovery greatly reduces the chance of losing a run due to a temporary sensor glitch.

---

# 5. EV3 I²C Protocol — Receiving Commands

```cpp
void receiveData(int byteCount) {
  while (EV3Wire.available() > 0) {
    lastCmd = EV3Wire.read();
    cmdReady = true;
  }
}
```

From the EV3’s point of view, this board behaves like a simple I²C sensor. The EV3 can write one or more bytes to the sensor as commands and can read bytes back as sensor values. The `receiveData()` function is registered as the I²C `onReceive` callback for the EV3-facing bus, so it is invoked automatically every time the EV3 writes data to this device.

Inside the function, the code reads all available bytes from the EV3 and stores the last one it sees in `lastCmd`. This design assumes that the EV3 will send a single command code per transaction, which is typical for EV3-style sensors. By keeping only the most recent byte and ignoring any others, the code remains simple and avoids needing a complex protocol parser. After reading the byte, the function sets `cmdReady` to `true`, indicating to the main loop that a new command is waiting to be processed. The main loop then reads `lastCmd` and reacts accordingly, for example by re-zeroing the yaw when it receives a specific command code.

This approach keeps the interrupt-like callback very short and avoids doing any heavy processing while I²C communication is in progress. That, in turn, helps prevent bus lock-ups or interference with other sensors that might be sharing the EV3’s I²C lines.

---

# 6. EV3 I²C Protocol — Sending Yaw Data

```cpp
void sendData() {
  int32_t centi = (int32_t)roundf(accumYaw * 100.0f);

  uint8_t buf[4];
  buf[0] = (uint8_t)(centi & 0xFF);
  buf[1] = (uint8_t)((centi >> 8) & 0xFF);
  buf[2] = (uint8_t)((centi >> 16) & 0xFF);
  buf[3] = (uint8_t)((centi >> 24) & 0xFF);

  EV3Wire.write(buf, 4);
}
```

The `sendData()` function is the counterpart to `receiveData()` and is registered as the `onRequest` callback for the EV3-side I²C bus. The EV3 triggers this callback whenever it performs a read operation on the sensor. At that moment, the firmware must supply the current yaw value formatted as four bytes.

First, the function multiplies the continuous yaw angle `accumYaw` by 100 and rounds it to the nearest integer, producing a signed 32-bit value in centi-degrees. This representation preserves two decimal places of precision without requiring floating point on the EV3 side. It then packs this 32-bit integer into a four-byte buffer in little-endian order, placing the least significant byte at index zero. Finally, it writes those four bytes onto the I²C bus so the EV3 can read them in a single transaction.

On the EV3, reconstructing the original yaw value is straightforward: the program combines the four bytes into a signed 32-bit integer, then divides by 100.0 to recover the angle in degrees. Because this value comes from `accumYaw`, it represents the same continuous heading that the firmware maintains internally and can grow beyond ±360° as the robot rotates multiple times.

---

# 7. setup() — Initializing Everything

```cpp
void setup() {
  Serial.begin(115200);

  EV3Wire.begin(SLAVE_ADDRESS, EV3_SDA, EV3_SCL, 100000);
  EV3Wire.onReceive(receiveData);
  EV3Wire.onRequest(sendData);

  Wire.begin();
  Wire.setClock(400000);

  hwResetIfAvailable();

  if (!startBNO()) {
    currentAddr = 0x4B;
    hwResetIfAvailable();
    startBNO();
  }
}
```

The `setup()` function configures both the EV3-facing I²C bus and the IMU-facing I²C bus, prepares serial debugging, and initializes the BNO08x IMU. It first opens a serial port at 115200 baud, which is extremely useful for debugging and verifying sensor behavior during development.

Next, it initializes the EV3-facing I²C bus by calling `EV3Wire.begin()` with the slave address and the SDA/SCL pin assignments. The chosen clock rate is 100 kHz, which is compatible with the EV3’s sensor port. The code then attaches the `receiveData()` callback for EV3 write operations and the `sendData()` callback for EV3 read operations, enabling the sensor to react automatically whenever the EV3 communicates.

For the IMU, the firmware uses the primary `Wire` I²C bus, which is initialized with `Wire.begin()` and set to 400 kHz using `Wire.setClock(400000)`. This higher speed helps achieve smooth and timely updates from the BNO08x. After a brief hardware reset delay, the code calls `startBNO()` to initialize the IMU at the default address. If that attempt fails, the address is switched to `0x4B`, and the IMU is reset and started again. This provides robustness in case the BNO08x module is configured at a different address than expected.

---

# 8. Main Loop — Commands, IMU Events & Yaw Integration

The main loop of the firmware orchestrates three core responsibilities: it handles any pending commands from the EV3, it processes all available events from the IMU, and it maintains a watchdog timer that detects when the IMU has stopped sending data. Together, these operations keep the continuous yaw estimate up to date and ensure that the sensor recovers from faults automatically.

## 8.1 Processing EV3 Commands

```cpp
void loop() {

  // 1. Handle EV3 command(s)
  if (cmdReady) {
    int cmd = lastCmd;
    cmdReady = false;

    if (cmd == 0x01) { // Re-zero yaw
      firstYawSet = false;
      accumYaw = 0.0f;
      lastYaw  = 0.0f;
    }
  }
```

At the start of each iteration, the loop checks whether a new command has arrived from the EV3 by looking at `cmdReady`. If this flag is set, it copies `lastCmd` into a local variable, clears the flag, and then interprets the command. In this example, the command `0x01` is reserved for re-zeroing the yaw. When that command is received, the firmware clears the yaw state, setting `firstYawSet` to `false` and resetting both `accumYaw` and `lastYaw` to zero. On the next valid IMU reading, the current physical orientation will become the new zero reference. This is particularly useful in competition runs where the robot is aligned to a wall or a line before starting.

## 8.2 Checking IMU Connectivity

```cpp
  // 2. Check IMU connectivity
  if (!imu.isConnected()) {
    static uint32_t lastTry = 0;
    if (millis() - lastTry > 1000) {
      lastTry = millis();
      recover();
    }
    delay(1);
    return;
  }

  bool gotAny = false;
```

After processing commands, the loop checks whether the IMU is still connected by calling `imu.isConnected()`. If the IMU appears disconnected, the code throttles recovery attempts so that it only tries to recover once per second, using a static timestamp `lastTry`. Within this disconnected state, the function calls `recover()` when the interval has elapsed, then briefly delays and returns early. This prevents the rest of the loop from using invalid IMU data and provides a clean reentry once the IMU is back online.

## 8.3 Reading IMU Events and Handling Resets

```cpp
  // 3. Read all available IMU events
  while (imu.getSensorEvent()) {
    gotAny = true;

    // 3a. IMU has reset - reconfigure and zero again
    if (imu.wasReset()) {
      configureReports();
      firstYawSet = false;
      accumYaw = 0.0f;
      lastYaw  = 0.0f;
    }

    // 4. Process rotation vector (quaternion → yaw)
    if (imu.sensorValue.sensorId == SH2_ROTATION_VECTOR) {
      float rawYaw = quatToYawDeg(
        imu.getQuatReal(),
        imu.getQuatI(),
        imu.getQuatJ(),
        imu.getQuatK()
      );
```

The loop then enters a `while` loop that repeatedly calls `imu.getSensorEvent()` to pull all pending events from the IMU. This ensures that no events pile up and that the heading estimate remains responsive. Whenever at least one event is retrieved, the `gotAny` flag is set to `true` so the watchdog knows that data is still flowing.

If the IMU indicates that it has reset (for example, due to an internal watchdog or power dip), `imu.wasReset()` will return `true`. In this case, the firmware re-enables the rotation vector reports by calling `configureReports()` and resets the yaw state, effectively treating the IMU reset as a fresh start. For each rotation vector event, the quaternion is converted into a raw yaw angle using `quatToYawDeg()`, which becomes the input to the yaw integration logic.

## 8.4 Yaw Initialization & Continuous Integration

```cpp
      // First valid sample sets yaw offset
      if (!firstYawSet) {
        yawOffset = rawYaw;
        lastYaw   = 0.0f;
        accumYaw  = 0.0f;
        firstYawSet = true;
      }

      // 5. Normalize yaw to [-180, 180]
      float yaw = rawYaw - yawOffset;
      while (yaw > 180) yaw -= 360;
      while (yaw < -180) yaw += 360;

      // Compute delta, handling wrap-around
      float delta = yaw - lastYaw;
      if (delta > 180)  delta -= 360;
      if (delta < -180) delta += 360;

      // Integrate into continuous yaw
      accumYaw += delta;
      lastYaw = yaw;
    }
  }
```

The yaw processing logic begins by checking whether a valid yaw reference has been established. On the very first valid IMU sample, `firstYawSet` is still `false`, so the code stores the current `rawYaw` as `yawOffset` and resets `lastYaw` and `accumYaw` to zero. It then sets `firstYawSet` to `true`, so subsequent samples will be treated as relative angles around this initial reference.

For each subsequent event, the code subtracts `yawOffset` from `rawYaw` to obtain a relative yaw angle. It then normalizes this yaw to the range from −180° to +180° by adding or subtracting 360° as needed. This normalization makes the angle more numerically stable and easier to work with.

Next, the code computes the difference `delta` between the current yaw and the last yaw. Because yaw wraps around at ±180°, a naïve difference might appear large even when the actual movement was small. To correct this, the code adjusts `delta` whenever it exceeds 180° in magnitude by adding or subtracting 360°, effectively undoing the wrap-around. Finally, it adds `delta` to `accumYaw`, producing an integrated continuous angle, and stores the current yaw as `lastYaw` for the next iteration. Over time, this approach builds a continuous yaw value that can track multiple full rotations in either direction.

## 8.5 Watchdog: No Data Recovery

```cpp
  // 6. Watchdog: no data → attempt recovery
  if (gotAny) {
    lastEventMs = millis();
  } else if (millis() - lastEventMs > noDataTimeoutMs) {
    recover();
  }

  delay(1);
}
```

At the end of the loop, the firmware updates the watchdog. If at least one IMU event was received during this iteration, it updates `lastEventMs` with the current time. If no events were received and the time since `lastEventMs` exceeds `noDataTimeoutMs`, the firmware assumes that the IMU has stopped sending data and calls `recover()` to restart it. A small delay of one millisecond is added to yield to other tasks and to avoid a tight, busy loop. This watchdog mechanism helps protect against silent failures where the IMU is still “connected” but no longer reporting data.

---

# 9. Yaw Normalization & Infinite Rotation (Detailed)

Internally, the BNO08x provides yaw as a wrapped angle, typically confined to the range between −180° and +180°. This is sufficient if you only care about the current physical orientation, but it is not enough when you want to know how many times a robot has rotated or to maintain a continuous heading value over long paths. The firmware addresses this gap by computing the difference between successive yaw measurements and integrating these differences over time.

On the first valid sample, the firmware records the initial yaw as `yawOffset` and treats this as the zero direction. Every subsequent raw yaw value is shifted by this offset, then normalized back into the −180°…+180° range. The difference between the current normalized yaw and the previous one is then computed. If that difference appears to be larger than 180° in magnitude, the code adjusts it by adding or subtracting 360°, which corrects for the wrap-around. That corrected difference is then added to `accumYaw`. Mathematically, the continuous yaw is the sum of all these corrected deltas, so as the robot spins multiple times, `accumYaw` grows accordingly and can represent multi-turn rotations without ever resetting.

---

# 10. Using the Sensor on the EV3 Side

From the EV3’s perspective, this device behaves like a simple I²C sensor that returns a four-byte signed integer. To read the current angle, the EV3 program performs an I²C read of four bytes from the configured sensor address. These bytes should be combined into a signed 32-bit integer using little-endian order (the first byte is the least significant). Once reconstructed, the value represents the angle in centi-degrees, so dividing it by 100.0 yields the yaw in standard degrees.

To reset the angle on demand, the EV3 writes a single byte with value `0x01` to the same I²C address. The firmware interprets this as a re-zero command, clears the yaw state, and treats the next valid IMU reading as the new zero direction. In most EV3 programming environments, such as EV3-G, Python on EV3, EV3Dev, or Pybricks, these reads and writes can be implemented using low-level I²C primitives, and once wrapped in a helper block or function, the sensor can be used much like a native gyro sensor that supports continuous headings.

---

# 11. Key Code Snippets (Quick Reference)

For quick reference, the following snippets highlight the most important structural elements of the firmware.

The core hardware and object definitions are:

```cpp
#define SLAVE_ADDRESS 0x04
#define EV3_SDA 12
#define EV3_SCL 11

TwoWire EV3Wire = TwoWire(1);
BNO08x imu;
uint8_t currentAddr = 0x4A;
```

The EV3 command reception callback is:

```cpp
void receiveData(int b) {
  while (EV3Wire.available()) {
    lastCmd = EV3Wire.read();
    cmdReady = true;
  }
}
```

The yaw transmission callback is:

```cpp
void sendData() {
  int32_t centi = (int32_t)roundf(accumYaw * 100);
  uint8_t b[4] = {
    (uint8_t)(centi & 0xFF),
    (uint8_t)((centi >> 8) & 0xFF),
    (uint8_t)((centi >> 16) & 0xFF),
    (uint8_t)((centi >> 24) & 0xFF)
  };
  EV3Wire.write(b, 4);
}
```

And the quaternion-to-yaw conversion helper is:

```cpp
static float quatToYawDeg(float w, float x, float y, float z) {
  float s = 2 * (w * z + x * y);
  float c = 1 - 2 * (y * y + z * z);
  return rad2deg(atan2f(s, c));
}
```

These pieces together define how the hardware is wired, how the EV3 talks to the sensor, and how the IMU’s quaternion output is turned into a usable heading.

---

# 12. Notes for Future WRO Engineers

This firmware is designed with competition conditions in mind. It is built to tolerate robot crashes, shaking cables, slightly loose connectors, and electrical noise from high-current motors, all while maintaining a valid yaw output. The automatic recovery system continuously monitors the IMU and attempts to restart it whenever communication is lost, which reduces the risk of losing a match because the gyro stopped responding.

During development or troubleshooting, you can use the serial monitor to print IMU event rates, inspect yaw values and deltas, detect unexpected IMU resets, and monitor how frequently the recovery system is activated. Observing the I²C bus usage on the EV3 side can also help prevent situations where too many sensors compete for bandwidth.

The firmware is compatible with common EV3 programming environments, including EV3-G, EV3 Python, EV3Dev, and Pybricks, and is well suited for WRO Open robots that need robust and precise heading control. If you want to extend the EV3 command protocol, you can easily add new command bytes such as `0x02` for a soft calibration, `0x03` for changing the update rate, `0x04` for freezing or unfreezing the output, or `0x05` for directly setting the yaw. Implementing these features typically requires only small additions to the command handling logic and corresponding changes in the main loop.

---

# END

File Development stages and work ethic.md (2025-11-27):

# 📘 **Development Stages (Engineering Overview)**  

---

## 📝 **1. Planning Phase**
Before building, we established a clear engineering direction to avoid wasted time and redesign loops.

**During this phase, we:**
- Defined the requirements of the WRO Future Engineers category and identified the technical functions our robot needed (accurate look-ahead sensing, smooth steering, stable behavior).
- Explored multiple steering mechanisms—**Ackermann and parallel**—and evaluated their geometric constraints and complexity.
- Sketched chassis concepts prioritizing **compactness, sensor visibility, and wiring accessibility**.
- Mapped out component placement, wheel sizing, motor orientation, and overall spatial constraints.
- Divided roles based on strengths:  
  **Kareem** on design, documentation, and sensory alignment;  
  **Adam** on coding, logic development, and control behavior.
- Built an iterative workflow centered on **prototype → test → document → optimize**.

> This planning stage created a solid foundation for a structured, engineering-focused development cycle.

---

## 🧭 **Background & Previous Experience**
Before entering the Future Engineers category, we built our foundation through years of self-driven learning and previous WRO participation. We are fully self-taught developers, and although this is our **first year** in Future Engineers, it is our **second year** competing in the WRO overall.

Our previous experience in the **RoboMission** category played a huge role in shaping our engineering mindset. The creative freedom of RoboMission forced us to approach problems with open-ended design thinking, which later became extremely valuable when building our obstacle-avoiding robot. It helped us develop a strong mechanical intuition, especially when designing compact robots under strict constraints.

We also gained experience in **line-following competitions**, where we pushed a LEGO EV3 system to its limits—breaking a **16-year standing record** using a finely tuned mathematical **PD control equation**. These challenges taught us precision, control theory, and efficient algorithm design.

Despite all these skills, the Future Engineers category introduced new obstacles:  
- camera placement and stabilization,  
- field-dependent calibration,  
- and even working with new mathematical concepts like **quadratic curve equations**.

These experiences shaped not only our workflow but also our determination to continuously adapt, learn, and engineer better solutions.

---

## 💡 **2. Concept Development**
Once the plan was set, we refined our ideas into early mechanical models and layout options.

**Our goals during concept development:**
- Create a chassis with enough turning freedom for tight maneuvers.
- Ensure the ultrasonic had a **clear forward “look-ahead” line**, crucial for fast reaction distance.
- Balance the robot’s size with maneuverability and mechanical simplicity.
- Identify weaknesses early through sketches and mini assemblies before committing to a full build.
- Prepare for multiple prototyping rounds with clear fallback options.

> Concept development gave us clarity on what to expect from each iteration and narrowed down our design path.

---

# 🛠️ **3. Prototyping Phase**

---

## 🔧 **Prototype V1 — Initial Exploration**

### **Engineering Characteristics**
- Ackermann steering paired with a differential drivetrain.  
- Medium motors mounted horizontally and stacked.  
- Steering geared down with bevel gears to smooth movements.  
- Spike wheels used for both drive and steering.  
- Ultrasonic sensor positioned **mid-chassis** due to blocked front space.

### **Issues Identified**
- Robot footprint became **too large**, reducing turning radius and limiting steering angle.  
- Large front wheels blocked us from adding ultrasonic sensors in the front.  
- The sensor being in the middle under the chassis created **late reaction time** for .....
- In open challenge tests, the robot frequently overcorrected due to inaccurate distance readings.

### ✅ **Engineering Insight from V1**  
Placing the ultrasonic at the front was essential.  
Ultrasonic sensor position was extremely inefficient and was the root problem of the robot

### 📷 **Prototype V1 Image**  
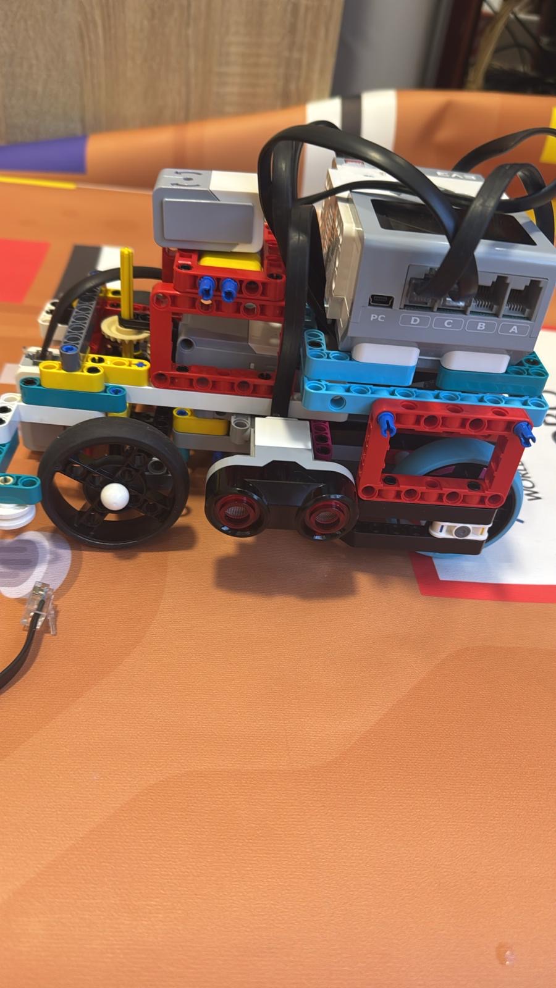
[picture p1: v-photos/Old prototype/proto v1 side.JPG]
Prototype V1


---

## 🔧 **Prototype V2 — Structural Redesign**

### **Major Engineering Changes**
- Motors reoriented **vertically**, reducing the width and freeing space.  
- Steering system replaced with simplified **parallel steering** geared from 8 tooth to 16 tooth bevel gear to increase encoder resolution..  
- Smaller wheels added in the front, allowing nearly **100° of steering rotation**.  
- First attempt at **direct steering drive** without gears.

### **Challenges Introduced**
- Direct steering became **too responsive**, causing overshoot, undershoot, and jittering.  
- Micro-movements translated instantly into large steering corrections.  
- Algorithm tuning became extremely sensitive and unstable.

### ✅ **Breakthrough Solution**
- Reintroducing **gear reduction** added a small amount of **mechanical backlash**, which unexpectedly **damped micro-corrections**.  
- This created **smoother, more predictable steering behavior** and simplified algorithm tuning.

### ✅ **Engineering Insight from V2**  
Controlled mechanical imperfections—like backlash—can **stabilize** control loops instead of harming them.

### 📷 **Prototype V1 vs V2 Comparison**  
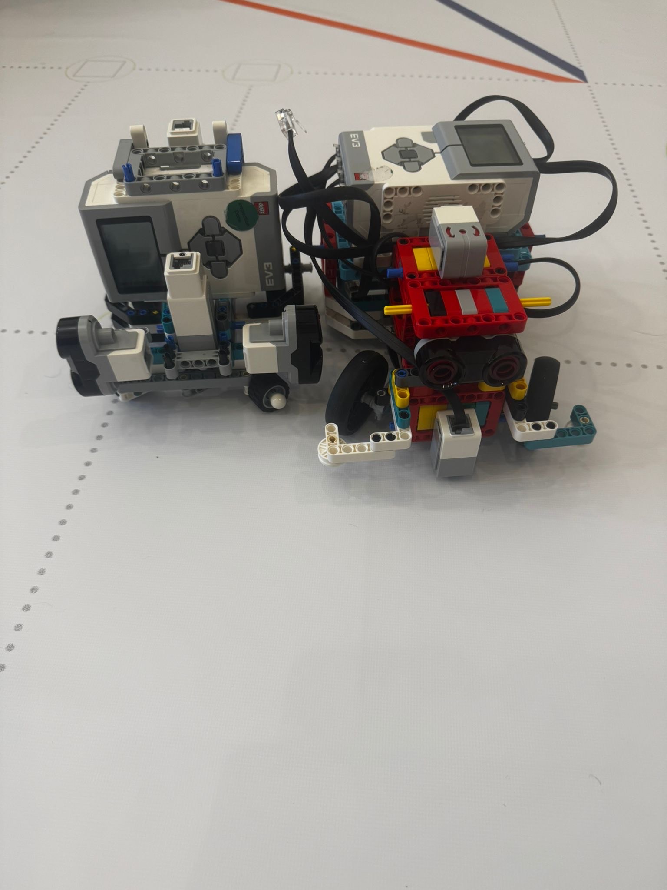
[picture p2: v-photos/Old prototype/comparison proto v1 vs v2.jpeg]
V1 vs V2


---

# 📊 **4. Testing & Evaluation**

### **Testing Focus Areas**
- Sensor reaction time after enabling forward look-ahead.  
- Steering stability across different correction frequencies.  
- Influence of wheel sizes and angles on maneuverability.  
- Chassis balance and structural vibration during sharp turns.  
- Repeatability across multiple test runs.

### ✅ **What Testing Revealed**
- Front-mounted ultrasonic dramatically improved reaction timing.  
- Parallel steering with small amount backlash provided the smoothest, most consistent control.  
- Compact front geometry enabled tighter steering without mechanical strain.

---

# 🔧 **5. Optimization Phase**
After identifying successful configurations, we refined the design for robust performance.

**Key optimizations included:**
- Fine steering tuning around the backlash window for predictable corrections.  
- Improved sensor alignment (camera + ultrasonic) for consistent visibility.  
- Rebalancing weight to reduce drift and uneven turns.  
- Cleaning wiring paths to prevent obstruction and simplify debugging.  
- Simplifying subsystems for easier maintenance and quick adjustments.

---

# 🚀 **6. Application Phase**
This is where the robot moved from “working prototype” to “competition-ready system.”

**Application achievements:**
- Algorithms were adapted to work *with* mechanical backlash, not against it.  
- Sensor data and steering logic were combined to create stable, early reactions to obstacles.  
- Mechanical behavior and software tuning were synchronized for predictable, repeatable runs.  
- The final robot delivered consistent performance across different field setups and lighting conditions.

### 📷 **Final V3 Isometric View**  
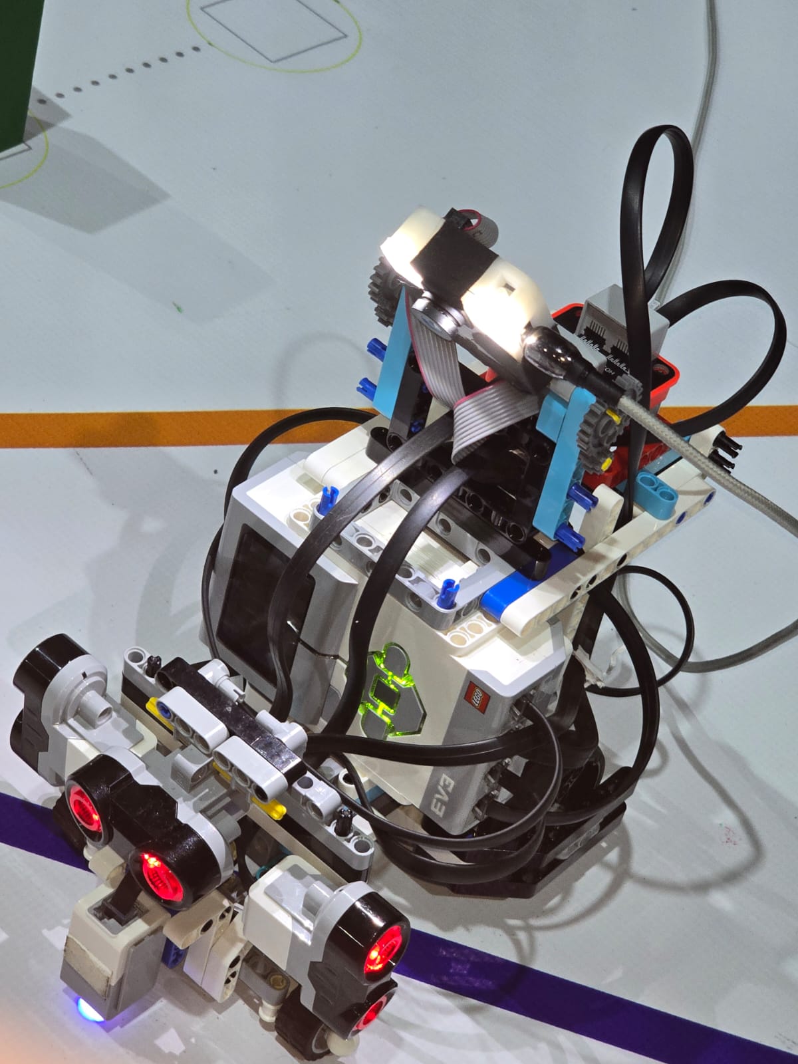
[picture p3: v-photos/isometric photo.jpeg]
V3 Isometric


---
# ❗ **Issues faced in International practice day**
-We found out that there was a strong magnetic field around the maps, therefore we decided to disable the magnetometer inside our gyro and used only accelerometer and the gyro. This helped remove the effect of the electromagnetic field on our robot.

# 🤝 **Work Ethic & Team Collaboration**

## **Team Collaboration**
- Tasks were divided logically—coding (Adam), design & documentation (Kareem)—but both of us contributed to each other’s work whenever needed.  
- Working in the same environment allowed rapid testing, immediate feedback, and fast iteration cycles.  
- Difficult problems were solved together by combining hardware and software perspectives.

## **Problem-Solving Approach**
1. Identify the issue  
2. Break it into manageable components  
3. Test a targeted solution  
4. Evaluate results  
5. Iterate until stable  

## **Documentation Practice**
- Detailed notes after each test  
- Photos capturing build stages  
- Logs of mechanical and algorithmic changes  
- Failures documented as carefully as successes  

## **Core Values**
- **Dedication:** long work sessions with constant iteration  
- **Consistency:** daily improvements and disciplined routine  
- **Curiosity:** exploring unconventional fixes (like using backlash)  
- **Team Unity:** always supporting each other  
- **Reflection:** learning from every result to guide the next step  

--

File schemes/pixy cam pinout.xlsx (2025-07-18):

Pixy camera pinout
Pixy 2 | EV3 cable
GND (6) | Red wire GND
5V(in n out) | Green wire (4.3V)
I2C SCL | Yellow wire (SCL)
I2C SDA | Blue wire (SDA)
/ | white wire Ignore
/ | black wire ignore

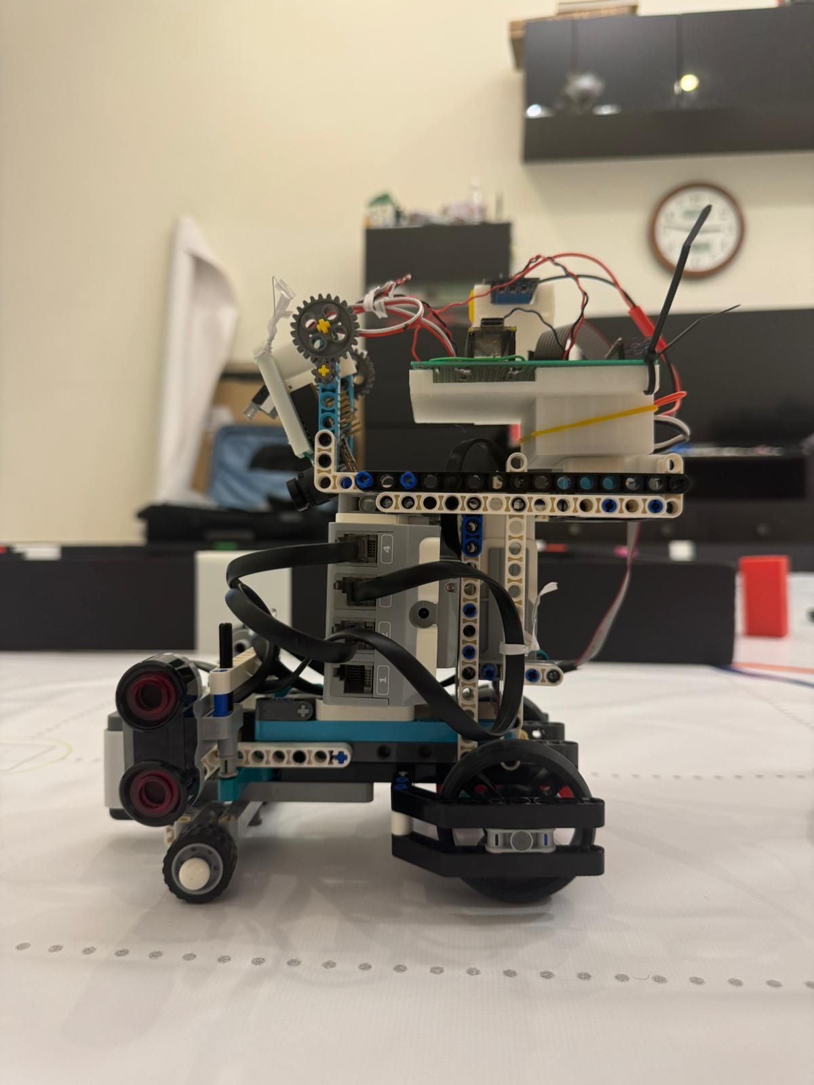
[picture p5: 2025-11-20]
v-photos/left.jpeg

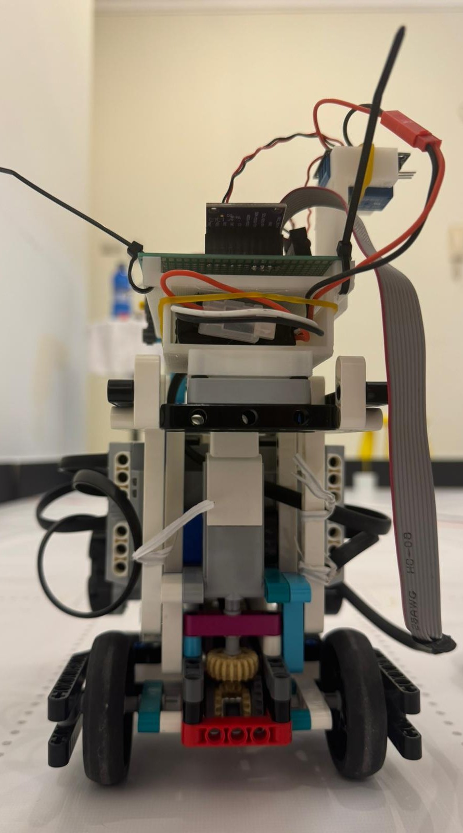
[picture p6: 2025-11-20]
v-photos/back.jpeg

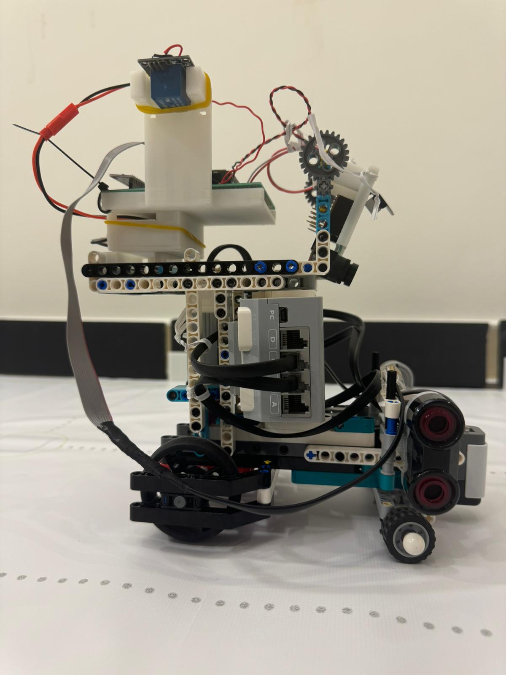
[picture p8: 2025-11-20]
v-photos/right.jpeg

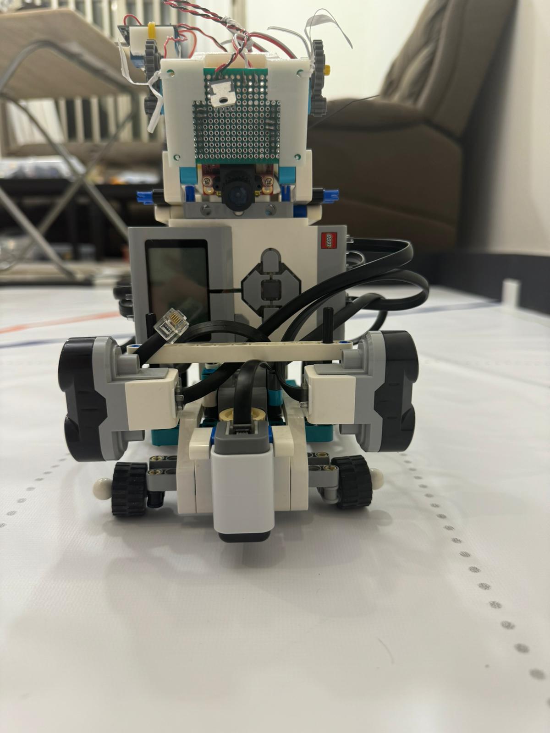
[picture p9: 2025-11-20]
v-photos/front.jpeg

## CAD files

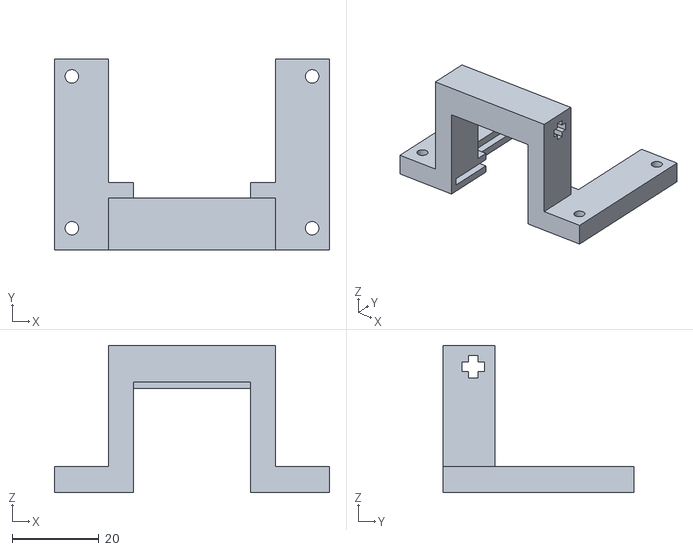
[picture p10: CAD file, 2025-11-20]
models/Camera holder.stl
63.4 x 44.0 x 34.0

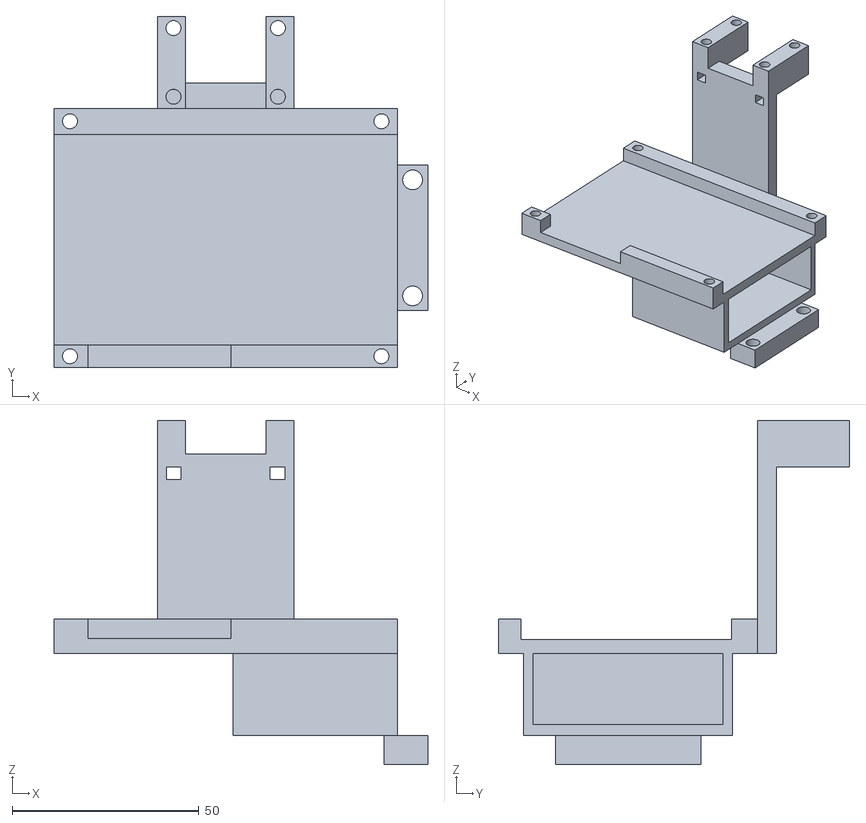
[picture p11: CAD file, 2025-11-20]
models/PCB and external battery holder.stl
100.2 x 94.1 x 92.3

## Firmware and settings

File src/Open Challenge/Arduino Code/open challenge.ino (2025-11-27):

#include <Wire.h>
#include <SparkFun_BNO08x_Arduino_Library.h>

// ---------------------- EV3 <-> Arduino (I2C Slave on Wire1) ----------------------
#define SLAVE_ADDRESS 0x04
#define EV3_SDA 12   // EV3 bus SDA -> D12
#define EV3_SCL 11   // EV3 bus SCL -> D11

TwoWire EV3Wire = TwoWire(1); // second I2C controller for EV3 link (slave)

// ---------------------- BNO085 on default I2C (Wire, A4/A5) -----------------------
BNO08x imu;
const int PIN_RST = -1;  // wire if you have it, else -1
const int PIN_INT = -1;  // optional INT (recommended), else -1

static inline float rad2deg(float r) { return r * 180.0f / PI; }
static float quatToYawDeg(float w, float x, float y, float z) {
  float s = 2.0f * (w * z + x * y);
  float c = 1.0f - 2.0f * (y * y + z * z);
  return rad2deg(atan2f(s, c));
}

// ---- IMU settings ----
uint8_t currentAddr = 0x4A;                // 0x4B if PS0 is HIGH
const uint16_t reportIntervalMs = 20;      // 50 Hz
const uint32_t noDataTimeoutMs = 1000;
uint32_t lastEventMs = 0;

// ---- yaw tracking (shared with EV3 callbacks) ----
volatile float accumYaw = 0.0f;            // unbounded
float yawOffset = 0.0f;
float lastYaw = 0.0f;
bool firstYawSet = false;

// ---------------------- EV3 command state ----------------------
volatile int lastCmd = 0;
volatile bool cmdReady = false;

// ======================================================================
//                           BNO085 helpers (on Wire)
// ======================================================================
void hwResetIfAvailable() {
  if (PIN_RST >= 0) {
    pinMode(PIN_RST, OUTPUT);
    digitalWrite(PIN_RST, LOW);
    delay(5);
    digitalWrite(PIN_RST, HIGH);
    delay(300);
  } else {
    delay(300);
  }
}

// Use GAME ROTATION VECTOR (gyro + accel, NO magnetometer)
bool configureReports() {
  // SparkFun API: enableReport(sensorId, interval_us)
  if (!imu.enableReport(SH2_GAME_ROTATION_VECTOR, reportIntervalMs * 1000UL)) {
    return false;
  }
  return true;
}

bool startBNO() {
  // Begin on default Wire (A4/A5). INT/RST if you wired them.
  bool ok = imu.begin(currentAddr, Wire,
                      (PIN_INT >= 0 ? PIN_INT : -1),
                      (PIN_RST >= 0 ? PIN_RST : -1));
  if (!ok) return false;

  if (!configureReports()) {
    Serial.println(F("Failed to enable Game Rotation Vector."));
  }

  lastEventMs = millis();
  // re-zero on each fresh start
  firstYawSet = false;
  accumYaw = 0.0f;
  lastYaw   = 0.0f;
  return true;
}

void recover() {
  Serial.println(F("\n[WARN] No IMU data; recovering..."));
  hwResetIfAvailable();
  if (!startBNO()) {
    currentAddr = (currentAddr == 0x4A) ? 0x4B : 0x4A;
    hwResetIfAvailable();
    if (!startBNO()) {
      Serial.println(F("[ERR] Re-init failed. Check wiring/power."));
    }
  } else {
    Serial.println(F("[OK] Recovered."));
  }
}

// ======================================================================
//                      EV3 I2C slave callbacks (Wire1)
// ======================================================================
void receiveData(int byteCount) {
  while (EV3Wire.available() > 0) {
    lastCmd = EV3Wire.read();
    cmdReady = true;
  }
  // Commands: 0x01 -> re-zero yaw
}

void sendData() {
  // 32-bit signed centi-degrees (deg * 100)
  int32_t centi = (int32_t)roundf(accumYaw * 100.0f);

  uint8_t buf[4];
  // Little-endian: least significant byte first
  buf[0] = (uint8_t)(centi & 0xFF);
  buf[1] = (uint8_t)((centi >> 8) & 0xFF);
  buf[2] = (uint8_t)((centi >> 16) & 0xFF);
  buf[3] = (uint8_t)((centi >> 24) & 0xFF);

  EV3Wire.write(buf, 4);
}

// ======================================================================
//                                 setup
// ======================================================================
void setup() {

  Serial.begin(115200);
  pinMode(LED_BUILTIN, OUTPUT);
  digitalWrite(LED_BUILTIN, HIGH);
  Serial.println(F("\n=== Nano ESP32: IMU on A4/A5, EV3 on D12/D11 ==="));
 
  // -------- EV3 I2C slave on Wire1 (D12/D11) --------
  EV3Wire.begin((uint8_t)SLAVE_ADDRESS, EV3_SDA, EV3_SCL, 100000);  // 100kHz for EV3
  EV3Wire.onReceive(receiveData);
  EV3Wire.onRequest(sendData);
  Serial.println(F("EV3 I2C slave ready @ 0x04 on D12/D11"));

  // -------- IMU I2C master on Wire (A4/A5) --------
  Wire.begin();            // board’s default SDA/SCL (A4/A5 on Nano layout)
  Wire.setClock(400000);   // 400k if wiring is short/clean; 100k if long
  hwResetIfAvailable();

  if (!startBNO()) {
    Serial.println(F("BNO085 not detected at 0x4A; trying 0x4B..."));
    currentAddr = 0x4B;
    hwResetIfAvailable();
    if (!startBNO()) {
      Serial.println(F("BNO085 not detected at either address."));
    } else {
      Serial.println(F("BNO085 detected at 0x4B."));
    }
  } else {
    Serial.print(F("BNO085 detected at 0x"));
    Serial.println(currentAddr, HEX);
  }

  Serial.println(F("Streaming zeroed, accumulated yaw (Game RV); EV3 reads 4-byte centi-deg.\n"));
}

// ======================================================================
//                                  loop
// ======================================================================
void loop() {
  // Handle EV3 commands (e.g., re-zero)
  if (cmdReady) {
    int cmd = lastCmd;
    cmdReady = false;
    if (cmd == 0x01) {
      firstYawSet = false;
      accumYaw = 0.0f;
      lastYaw  = 0.0f;
      Serial.println(F("[CMD] Re-zero yaw"));
    }
  }

  // IMU connected?
  if (!imu.isConnected()) {
    static uint32_t lastTry = 0;
    if (millis() - lastTry > 1000) {
      lastTry = millis();
      recover();
    }
    delay(1);
    return;
  }

  bool gotAny = false;

  // Drain all pending IMU events
  while (imu.getSensorEvent()) {
    gotAny = true;

    if (imu.wasReset()) {
      Serial.println(F("[INFO] IMU reset. Re-configuring reports + re-zero..."));
      configureReports();
      firstYawSet = false;
      accumYaw = 0.0f;
      lastYaw  = 0.0f;
    }

    // Use GAME ROTATION VECTOR events (no magnetometer)
    if (imu.sensorValue.sensorId == SH2_GAME_ROTATION_VECTOR) {
      float x = imu.getQuatI();
      float y = imu.getQuatJ();
      float z = imu.getQuatK();
      float w = imu.getQuatReal();
      float rawYaw = quatToYawDeg(w, x, y, z);

      // First valid reading defines zero
      if (!firstYawSet) {
        yawOffset = rawYaw;
        lastYaw   = 0.0f;
        accumYaw  = 0.0f;
        firstYawSet = true;
      }

      // Zeroed yaw
      float yaw = rawYaw - yawOffset;

      // Normalize to -180..180
      while (yaw > 180.0f) yaw -= 360.0f;
      while (yaw < -180.0f) yaw += 360.0f;

      // Delta with wrap-around handling
      float delta = yaw - lastYaw;
      if (delta > 180.0f) delta -= 360.0f;
      if (delta < -180.0f) delta += 360.0f;

      // Accumulate (unbounded)
      accumYaw += delta;
      lastYaw = yaw;

      // Optional debug
      static uint32_t lastPrint = 0;
      if (millis() - lastPrint >= 200) {
        lastPrint = millis();
        Serial.print(F("AccumYaw: "));
        Serial.print(accumYaw, 2);
        Serial.print(F(" deg | Yaw (zeroed): "));
        Serial.println(yaw, 2);
      }
    }
  }

  if (gotAny) {
    lastEventMs = millis();
  } else if (millis() - lastEventMs > noDataTimeoutMs) {
    recover();
  }

  delay(1);
}

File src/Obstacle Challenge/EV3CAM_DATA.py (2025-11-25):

from machine import UART, LED
import sensor
import time

# ================================
# CONFIGURATION
# ================================
LINE_OFFSET = 159   # distance from center in pixels
LEFT_LINE_COLOR  = (255, 0, 0)    # Red
RIGHT_LINE_COLOR = (0, 255, 0)    # Green
CENTER_COLOR     = (0, 0, 255)
BLUE_LINE_COLOR  = (0, 0, 255)

# Y-threshold: ignore all blobs ABOVE this line (for detection + drawing)
Y_IGNORE_THRESHOLD = 30

#ROI unused
BOX_WIDTH   = 50
BOX_HEIGHT  = 50
BOX_Y_SHIFT = 70
BOX_X_DEVIATION = BOX_WIDTH // 2

SIDE_BOX_WIDTH   = 110
SIDE_BOX_HEIGHT  = 60
SIDE_BOX_Y_SHIFT = 70
SIDE_BOX_X_DEVIATION = SIDE_BOX_WIDTH // 2
ROI_X_SHIFT = 120

# Low-pass filter settings
LPF_ALPHA = 0.8
LPF_RESET_LOOPS = 7

# LED setup
led = LED("LED_GREEN")
led.on()

# Color Tracking Thresholds
thresholds = [
    (3, 29, 7, 36, 4, 21),       # RED
    (20, 60, -28, -7, 4, 27),    # GREEN
    (55, 72, 26, 48, -19, -7),    # MAGENTA
]

# Bit codes
RED_CODE     = 1
GREEN_CODE   = 2
MAGENTA_CODE = 4

uart = UART(1, 19200, timeout_char=100)

CODE_TO_COLOR = {
    RED_CODE:     (255,   0,   0),
    GREEN_CODE:   (0,   255,   0),
    MAGENTA_CODE: (255, 105, 180),
}

# ================================
# CAMERA SETUP
# ================================
sensor.reset()
sensor.set_pixformat(sensor.RGB565)
sensor.set_framesize(sensor.QVGA)  # 320x240
sensor.set_vflip(True)
sensor.set_hmirror(True)
sensor.skip_frames(time=2000)
sensor.set_auto_exposure(False, exposure_us=100000)
sensor.set_auto_gain(False)
sensor.set_auto_whitebal(False)

clock = time.clock()
time.sleep_ms(500)

# ================================
# UTILS: BOUNDING BOX CENTER
# ================================
def bbox_center(b):
    # Center of the rectangle (x + w/2, y + h/2)
    return b.x() + b.w() // 2, b.y() + b.h() // 2

# ================================
# FIND OBSTACLES + MAGENTA
# ================================
def find_largest_obstacle_and_magenta(img):
    largest_obstacle = None
    largest_obstacle_sig = 6    # 6 = no obstacle
    largest_obstacle_area = -1

    best_magenta = None
    best_magenta_area = -1

    cx0 = img.width() // 2
    cy0 = img.height() // 2

    
    blobs = img.find_blobs(thresholds, pixels_threshold=100, area_threshold=100, merge=False)

    for b in blobs:
        code = b.code()
        area = b.pixels()
        w = b.w()
        h = b.h()

        # use bounding-box center instead of centroid
        bx, by = bbox_center(b)

        # IGNORE ANY BLOB ABOVE THE Y-THRESHOLD
        if by < Y_IGNORE_THRESHOLD:
            continue

        # OBSTACLE CANDIDATE: RED OR GREEN
        if code & (RED_CODE | GREEN_CODE):

            # Ignore red blobs that are wider than tall
            if (code & RED_CODE) and (w > h):
                continue

            sig = 1 if (code & RED_CODE) else 2

            if area > largest_obstacle_area:
                largest_obstacle_area = area
                largest_obstacle = b
                largest_obstacle_sig = sig

        # MAGENTA (does NOT affect sig)
        if code & MAGENTA_CODE:
            if area > best_magenta_area:
                best_magenta_area = area
                best_magenta = b

    # RETURN OBSTACLE
    if largest_obstacle is None:
        obstacle = (0, 0, 0, 0, 6)  # sig = 6
    else:
        bx, by = bbox_center(largest_obstacle)
        obstacle = (
            bx - cx0,
            by - cy0,
            largest_obstacle.w(),
            largest_obstacle.h(),
            largest_obstacle_sig
        )

    # RETURN MAGENTA
    if best_magenta is None:
        magenta = (0, 0, 0, 0)
    else:
        mx, my = bbox_center(best_magenta)
        magenta = (
            mx - cx0,
            my - cy0,
            best_magenta.w(),
            best_magenta.h()
        )

    return obstacle, magenta, blobs

# ================================
# UART SENDER (UNCHANGED FORMAT)
# ================================
def send_uart_error_magenta(uart, error, osig, magenta):
    mcx, mcy, mw, mh = magenta
    uart.write("D,{},{},{},{},{},{}\n".format(int(error), int(osig), mcx, mcy, mw, mh))

# ================================
# LPF STATE
# ================================
filtered_ocx_rel = 0.0
lpf_loop_count = 0
last_sig = 6

# ================================
# MAIN LOOP
# ================================
while True:
    clock.tick()
    img = sensor.snapshot()

    obstacle, magenta, blobs = find_largest_obstacle_and_magenta(img)

    cx = img.width() // 2
    cy = img.height() // 2
    img.draw_cross(cx, cy, color=CENTER_COLOR, size=10)

    x_left  = cx - LINE_OFFSET
    x_right = cx + LINE_OFFSET

    # Left and right lines only
    img.draw_line(x_left, 0, x_left, img.height()-1, color=LEFT_LINE_COLOR, thickness=2)
    img.draw_line(x_right, 0, x_right, img.height()-1, color=RIGHT_LINE_COLOR, thickness=2)

    # DRAW Y-IGNORE BLUE LINE (visual only)
    img.draw_line(0, Y_IGNORE_THRESHOLD, img.width(), Y_IGNORE_THRESHOLD,
                  color=BLUE_LINE_COLOR, thickness=2)

    # Extract obstacle data
    ocx_rel, ocy_rel, ow, oh, osig = obstacle  # osig = 1 red, 2 green, 6 none
    base_sig = osig  # keep the original color code for internal logic

    error = 0
    too_close = 0  # kept only for printing/debug; no safety logic now

    # ================================
    # OBSTACLE FOUND
    # ================================
    if base_sig == 1 or base_sig == 2:

        # Absolute obstacle center of the *largest* obstacle (bbox-based)
        obstacle_abs_x = ocx_rel + cx
        obstacle_abs_y = ocy_rel + cy

        # No safety ROI / too_close checks anymore

        # ----- LPF (uses base_sig 1/2 only, unchanged) -----
        if base_sig != last_sig:
            filtered_ocx_rel = float(ocx_rel)
            lpf_loop_count = 0
        else:
            filtered_ocx_rel = (LPF_ALPHA * ocx_rel) + ((1.0 - LPF_ALPHA) * filtered_ocx_rel)
            lpf_loop_count += 1
            if lpf_loop_count >= LPF_RESET_LOOPS:
                filtered_ocx_rel = float(ocx_rel)
                lpf_loop_count = 0

        obj_x = cx + filtered_ocx_rel
        line_x = x_left if base_sig == 1 else x_right
        error = obj_x - line_x

        # osig is just the base color (1 = red, 2 = green)
        osig = base_sig

    else:
        base_sig = 6
        osig = 6
        error = 0
        lpf_loop_count = 0
        too_close = 0

    # track last base color sig (1,2,6) for LPF behavior
    last_sig = base_sig

    print("error:", error, "sig:", osig,
          "too_close:", too_close, "mag:", magenta)

    # ================================
    # DRAW VALID BLOBS ONLY
    # ================================
    for blob in blobs:
        code = blob.code()

        # Skip red blobs wider than tall
        if (code & RED_CODE) and (blob.w() > blob.h()):
            continue
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

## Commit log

2025-11-09 Update README with links to 3D models and schematics
2025-11-19 Update README with link to old prototypes
2025-11-23 updated read me
    Add detailed documentation for Arduino to EV3 Gyro Bridge project, covering overview, hardware configuration, yaw integration, and recovery logic.
2025-11-25 updated cam logic
    Refactor obstacle detection and UART communication, improve blob filtering and add Y-threshold for detection.
2025-11-25 update gyro
2025-11-25 Reorganize README content for better readability
    Rearranged content for clarity and improved flow.
2025-11-25 Update README with improved explanations
    Clarified descriptions of sensor resets and final movement sequence.
2025-11-27 Document issues faced in International practice day
    Added a section on issues faced during International practice day, detailing the decision to disable the magnetometer due to a strong magnetic field.
2025-11-27 Update IMU configuration to use Game Rotation Vector
2025-11-27 Refactor gyro.h for improved IMU handling(no magnetometer
